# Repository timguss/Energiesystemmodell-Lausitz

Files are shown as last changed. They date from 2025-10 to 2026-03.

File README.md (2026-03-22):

# Energiesystemmodell Lausitz

An interactive, distributed control system for modeling and operating an energy system in the Lausitz region. The system enables real-time control of relays, sensors, motors, and actuators across multiple ESP32 microcontrollers through a Flask-based web interface.

---

## Table of Contents

- [Project Overview](#project-overview)
- [System Architecture](#system-architecture)
- [Features](#features)
- [Hardware Components](#hardware-components)
- [Software Stack](#software-stack)
- [Installation & Setup](#installation--setup)
- [Usage](#usage)
- [API Overview](#api-overview)
- [Project Structure](#project-structure)
- [Future Improvements](#future-improvements)
- [License](#license)

---

## Project Overview

The Energiesystemmodell Lausitz is a physical scale model of an energy system designed for educational and demonstration purposes. It simulates multiple energy sources and components — including a coal power plant, gas plant, electrolyzer, wind turbine, and model railway — all of which can be controlled and monitored in real time via a web-based dashboard.

The system consists of:
- **Multiple ESP32 client devices** that directly control relays, read sensors, and drive actuators
- **One ESP32 Host device** that acts as a central wireless gateway, receiving commands from the web server and forwarding them to the appropriate client via ESP-NOW
- **A Flask web server** (running on a Raspberry Pi or laptop) that exposes a REST API and serves the web UI

Users interact with the system through two frontend interfaces:
- A **landing page** with thematic system cards, scenario buttons, and live sensor values
- A **technical dashboard** for direct relay control, RS232 communication, and device diagnostics

---

## System Architecture

```
┌────────────────────────┐
│   Browser / User       │
│   (Landing / Dashboard)│
└──────────┬─────────────┘
           │ HTTP
┌──────────▼─────────────┐
│   Flask Server         │
│   (Raspberry Pi/Laptop)│
│   app.py + routes/     │
└──────────┬─────────────┘
           │ HTTP (WiFi AP)
┌──────────▼─────────────┐
│   ESP Host             │
│   (WiFi Access Point + │
│    ESP-NOW Gateway)    │
└──┬──────┬──────┬───┬───┘
   │      │      │   │
   │   ESP-NOW   │   │
┌──▼─┐ ┌──▼─┐ ┌─▼─┐ ┌▼──┐ ┌─▼─┐
│ESP1│ │ESP2│ │ESP3│ │ESP4│ │ESP5│
│8x  │ │4x  │ │4x  │ │5x  │ │7x  │
│Relay│ │Relay│ │Relay│ │Relay│ │Strip│
│NTC │ │NTC │ │Motor│ │5x  │ │    │
│RS232│ │    │ │Wind │ │Sensor│ │    │
└────┘ └────┘ └────┘ └────┘ └────┘
```

### Communication Flow

1. The **Flask server** receives HTTP requests from the browser.
2. It forwards commands to the **ESP Host** via HTTP (the Host runs a WebServer over its WiFi AP).
3. The **ESP Host** relays commands to the appropriate **ESP client** using **ESP-NOW** (a connectionless, peer-to-peer protocol that does not require a full TCP/IP stack).
4. Client ESPs send back **status messages** (heartbeats every 2 seconds + immediate ACKs on relay changes) to the Host via ESP-NOW broadcast.
5. The Host caches device states and serves them to the Flask server on demand.

### Why ESP-NOW?

ESP-NOW allows direct peer-to-peer communication between ESP32 devices without requiring a traditional WiFi connection on the client side. This reduces latency, eliminates the need for TCP/IP stack management on clients, and makes the system more robust against network instability.

---

## Features

- **Real-time relay control** — Toggle individual relays on any client ESP via the web UI
- **Scenario execution** — Execute multi-step action sequences (with delays) defined in `scenarios.json`
- **Sensor monitoring** — Live readings from 4–20 mA current-loop sensors calibrated to bar/cm values
- **Temperature monitoring** — NTC thermistor readings from ESP1 and ESP2
- **Flow measurement** — Pulse-counting flow meter on ESP4 (L/min)
- **Motor PWM control** — Variable-speed and direction control of a DC motor on ESP3
- **Wind pin control** — Digital on/off control of a wind output on ESP3
- **RS232 communication** — Send raw serial commands to an MFC (Mass Flow Controller) via ESP1
- **LED flow visualization** — Physical LED strips on ESP5 dynamically mirror website energy flows
- **ACK-based relay confirmation** — The Host waits up to 1500 ms for a relay state acknowledgment from the client before confirming success
- **Device online/offline tracking** — Automatic offline detection after 10 seconds without heartbeat
- **Two UI modes** — Thematic landing page for operators; technical dashboard for developers/engineers
- **Selective polling** — Frontend only polls devices that have previously been seen online, reducing unnecessary requests

---

## Hardware Components

### ESP32 Devices

| Device | Role | Relays | Special Functions |
|---|---|---|---|
| ESP Host | Central gateway / HTTP server | —  | WiFi AP, ESP-NOW hub |
| ESP1 | Gas plant controller | 8 | NTC temperature, RS232 (MFC)  |
| ESP2 | Coal plant controller | 4 | NTC temperature |
| ESP3 | Wind / Train controller  | 4 | DC motor (L298N), wind pin |
| ESP4 | Electrolyzer controller  | 5 | 5× 4–20 mA sensors, flow meter |
| ESP5 | LED Strip controller | — | 7× WS2812B strips for flows |

### Relays

- **ESP1:** Ventil-1, Ventil-2, Heizstab, Zünder, Gasventil, Kühler, MFC, (Unbelegt)
- **ESP2:** Kühler-Kohle, Ventil Turbine, Ventil-Kohle, Heizstab-Kohle
- **ESP3:** Relais 2–5 (general purpose)
- **ESP4:** Elektrolyseur (High-Trigger), Tank füllen, Tank leeren, Durchschalten, Lüfter

### Sensors & Actuators

| Component | Device | Interface | Notes |
|---|---|---|---|
| NTC Thermistors | ESP1, ESP2 | ADC (GPIO34) | β=3950, R₀=10kΩ, voltage divider with 10kΩ |
| 4–20 mA Sensors | ESP4 | ADC (5× pins) | 165Ω shunt resistor, calibrated per sensor |
| Pressure Sensors  | ESP4 | 4–20 mA | Sensors 0–2: pressure (bar) |
| Ultrasonic Sensors| ESP4 | 4–20 mA | Sensors 3–4: distance (cm) |
| Flow Meter | ESP4 | GPIO17 (interrupt) | Pulse-counting, NPN output, FALLING edge |
| DC Motor | ESP3 | L298N (PWM)  | ENA=GPIO32, IN1=GPIO25, IN2=GPIO26 |
| Wind Output | ESP3 | GPIO27 | Digital on/off |
| RS232 / MFC | ESP1 | UART2 (38400 baud) | RX=GPIO16, TX=GPIO17 |
| Standalone Pressure Sensors | External | ADC (GPIO 33–35) | 3× sensors, shared zero point |

---

## Software Stack

### Backend
- **Python 3** with **Flask 3.0**
- **Requests 2.31** for HTTP communication with the ESP Host
- Blueprint-based modular routing (`routes/relays.py`, `routes/scenarios.py`, `routes/leds.py`, `routes/esp3.py`, `routes/debug.py`)

### Frontend
- Vanilla **HTML5 / CSS3 / JavaScript** (no framework dependencies)
- Two pages: `landing.html` (operator UI) + `dashboard.html` (technical UI)
- Polling-based state updates (default: 3–5 second intervals)
- Google Fonts (Inter)

### ESP Firmware
- **Arduino framework** for ESP32 (Arduino IDE / PlatformIO)
- Libraries: `WiFi.h`, `esp_now.h`, `WebServer.h`, `esp_mac.h`

### Communication Protocols

| Layer | Protocol | Used Between |
|---|---|---|
| Browser → Flask | HTTP REST | Browser and Flask server |
| Flask → ESP Host | HTTP (port 80) | Flask server and ESP Host WiFi AP |
| ESP Host → Clients | ESP-NOW | ESP Host and ESP1–5 (peer-to-peer)  |
| ESP1 ↔ MFC | RS232 / UART2  | ESP1 and Mass Flow Controller |

---

## Installation & Setup

### Prerequisites

- Python 3.9+
- Arduino IDE (2.x recommended) or PlatformIO with ESP32 board support
- ESP32 boards flashed with the appropriate firmware

### 1. Flash the ESP Firmware

#### Step 1 — Flash client ESPs first

Flash each client ESP (`ESP_1`, `ESP_2`, `ESP_3`, `ESP_4`) with its corresponding `.ino` sketch. After flashing, open the Serial Monitor at **115200 baud** and note the MAC address printed on boot:

```
ESP-NOW MAC: AA:BB:CC:DD:EE:FF
```

#### Step 2 — Configure the Host

Open `ESP_Host/ESP_Host.ino` and enter the MAC addresses you recorded:

```cpp
uint8_t MAC_ESP1[6] = {0x84, 0x1F, 0xE8, 0x26, 0x58, 0xD8};
uint8_t MAC_ESP2[6] = {0x20, 0x43, 0xA8, 0x6A, 0xFB, 0xDC};
uint8_t MAC_ESP3[6] = {0x20, 0xE7, 0xC8, 0x6B, 0x4F, 0x18};
uint8_t MAC_ESP4[6] = {0x8C, 0x4F, 0x00, 0x2E, 0x59, 0xE8};
uint8_t MAC_ESP5[6] = {0x00, 0x00, 0x00, 0x00, 0x00, 0x00}; // Update with ESP5 MAC
```

Then flash the Host ESP.

#### ESP Host WiFi AP Credentials (default)

```
SSID:     ESP-HOST
Password: espHostPass
Channel:  1
```

> **Important:** ESP-NOW and the WiFi AP must operate on the same channel (channel 1 by default). All client ESPs must also use channel 1.

### 2. Set Up the Flask Server

#### Connect to the ESP Host's WiFi AP

Connect your Raspberry Pi or laptop to the `ESP-HOST` WiFi network.

#### Install Python dependencies

```bash
cd programmierung/website
pip install -r requirements.txt
```

#### Configure the host IP (if needed)

The default host IP is `http://192.168.4.1` (the ESP Host's AP address). Edit `config.py` if your setup differs:

```python
HOST = "http://192.168.4.1"
```

#### Run the Flask server

```bash
python app.py
```

The server starts on `http://0.0.0.0:8000`. Open a browser and navigate to `http://<raspberry-pi-ip>:8000`.

---

## Usage

### Web Interface

| URL | Description |
|---|---|
| `/` | Landing page — thematic system cards, scenarios, sensors |
| `/dashboard` | Technical dashboard — direct relay/motor/RS232 control |

### Scenario Execution

Scenarios are defined in `scenarios.json` as ordered lists of actions. Available action types:

| Type | Fields | Description |
|---|---|---|
| `relay` | `global_idx` or `name`, `val` | Switch a relay on (1) or off (0) |
| `delay` | `ms` | Wait for the given milliseconds |
| `wind`  | `val` | Turn wind output on or off |
| `train` | `pwm`, `dir` | Set motor speed and direction |

Example scenario definition:

```json
"kohlekraftwerk_startup": {
  "name": "Kohlekraftwerk Start",
  "actions": [
    { "type": "relay", "global_idx": 9, "val": 1 },
    { "type": "delay", "ms": 1500 },
    { "type": "relay", "global_idx": 10, "val": 1 }
  ]
}
```

### Global Relay Index Mapping

| Global Index | Device | Device Index | Name |
|---|---|---|---|
| 1–8 | ESP1 | 0–7 | Ventil-1 … Unbelegt |
| 9–12 | ESP2 | 0–3 | Kühler-Kohle … Heizstab-Kohle |
| 13–17 | ESP4 | 0–4 | Elektrolyseur … Lüfter |
| 18–21 | ESP3 | 0–3 | Relais 2–5 |

---

## API Overview

All endpoints are served by the Flask server on port 8000.

### Relay Control

| Method | Endpoint | Body / Params | Description |
|---|---|---|---|
| POST | `/api/relay/set` | `{ "global_idx": 1, "val": 1 }` | Set a relay on or off |

### Device State

| Method | Endpoint | Description |
|---|---|---|
| GET | `/api/device_state/<device>` | Get last known state of `esp1`–`esp4`  |
| GET | `/api/device_meta/<device>`  | Get relay count and names for a device |

**Example response for `esp4`:**
```json
{
  "code": 200,
  "body": {
    "relays": [0, 1, 0, 0, 1],
    "sensors": [
      { "current": 8.45, "pressure": 1.23 },
      ...
    ],
    "flow": 3.5
  },
  "offline": false
}
```

### Scenarios

| Method | Endpoint | Body | Description |
|---|---|---|---|
| GET | `/api/scenarios` | — | List all available scenarios |
| POST | `/api/scenario/execute` | `{ "scenario": "kohlekraftwerk_startup" }`  | Execute a scenario by key |

### ESP3 Controls

| Method | Endpoint | Body | Description |
|---|---|---|---|
| GET | `/api/esp3/state` | — | Get wind and motor state |
| POST | `/api/esp3/set_wind`  | `{ "val": 1 }` | Turn wind on or off |
| POST | `/api/esp3/set_pwm` | `{ "pwm": 128, "dir": 1 }` | Set motor speed/direction|

### RS232

| Method | Endpoint | Body | Description |
|---|---|---|---|
| POST | `/api/rs232`  | `{ "cmd": ":06030101213E80", "timeout": 500 }` | Send raw RS232 command via ESP1 |
| POST | `/api/leds/sync` | `{ "flows": { "coal": [true], ... } }` | Sync flows with ESP5 strips |
| POST | `/api/leds/test` | `{ "mode": "green" }` | Hardware test for all LEDs |

### Debug / Status

| Method | Endpoint | Description |
|---|---|---|
| GET | `/api/debug/host` | Check if the Host ESP is reachable |
| GET | `/api/clients` | Get online/offline status of all clients  |
| GET | `/api/sensors/meta`  | Get sensor configuration for the frontend |

---

## Project Structure

```
.
├── README.md
└── programmierung/
    ├── esp code/
    │   ├── ESP_Host/
    │   │   └── ESP_Host.ino         # Central gateway: WiFi AP + ESP-NOW hub + HTTP server
    │   ├── ESP_1/
    │   │   └── ESP_1.ino            # 8× relay, NTC temp, RS232 (MFC)
    │   ├── ESP_2/
    │   │   └── ESP_2.ino            # 4× relay, NTC temp
    │   ├── ESP_3/
    │   │   └── ESP_3.ino            # 4× relay, DC motor, wind output
    │   ├── ESP_4/
    │   │   └── ESP_4.ino            # 5× relay, 5× 4–20mA sensors, flow meter
    │   ├── ESP_5/
    │   │   └── ESP_5.ino            # 7× LED strip controller
    │   ├── Drucksensoren/
    │   │   └── Drucksensoren.ino    # Standalone pressure sensor test sketch
    │   ├── Ralays-4/
    │   │   └── Ralays-4.ino         # Simple 4-relay cycling test sketch
    │   └── tests/
    │       ├── layout.html          # Standalone HTML UI prototype
    │       └── test/
    │           └── test.ino         # Flow meter calibration sketch
    └── website/
        ├── app.py                   # Flask application entry point
        ├── config.py                # Central config: HOST, relay map, sensor calibration, scenarios
        ├── esp_client.py            # Low-level HTTP client for ESP Host communication
        ├── requirements.txt
        ├── scenarios.json           # Scenario definitions (actions, delays)
        ├── routes/
        │   ├── __init__.py
        │   ├── relays.py            # /api/relay/set, /api/device_state, /api/device_meta
        │   ├── scenarios.py         # /api/scenarios, /api/scenario/execute
        │   ├── esp3.py              # /api/esp3/*, /api/rs232
        │   └── debug.py             # /api/debug/host, /api/clients
        ├── static/
        │   ├── app.js               # Dashboard page JavaScript
        │   ├── landing.js           # Landing page JavaScript
        │   ├── style.css            # Dashboard styles
        │   └── landing.css          # Landing page styles
        └── templates/
            ├── dashboard.html       # Technical control dashboard
            └── landing.html         # Operator-facing landing page
```

---

## Future Improvements

- [ ] **WebSocket / Server-Sent Events** — Replace HTTP polling with push-based updates for lower latency and reduced server load
- [ ] **Authentication** — Add basic auth or token-based access control to the Flask API
- [ ] **Persistent state storage** — Log relay states and sensor readings to a database (e.g. SQLite or InfluxDB) for historical analysis
- [ ] **Flow meter calibration UI** — Allow the K_FACTOR to be set from the web UI without reflashing firmware
- [ ] **RS232 command library** — Build a structured command library for the MFC instead of raw hex input
- [ ] **Sensor calibration UI** — Allow `i_zero`, `i_full`, and `max_val` to be adjusted at runtime via the dashboard
- [ ] **ESP4 pressure display on landing page** — Wire up the existing sensor cards to show live pressure bar graphs
- [ ] **Scenario editor** — UI for creating and editing scenarios without manually editing `scenarios.json`
- [ ] **Multi-language support** — Currently the UI is in German; adding English would increase accessibility
- [ ] **OTA firmware updates** — Enable over-the-air updates for the ESP devices

---

## License

This project is currently unlicensed. Add a `LICENSE` file to define usage terms.

---

*Energiesystemmodell Lausitz — Interaktive Steuerung für erneuerbare Energiesysteme*

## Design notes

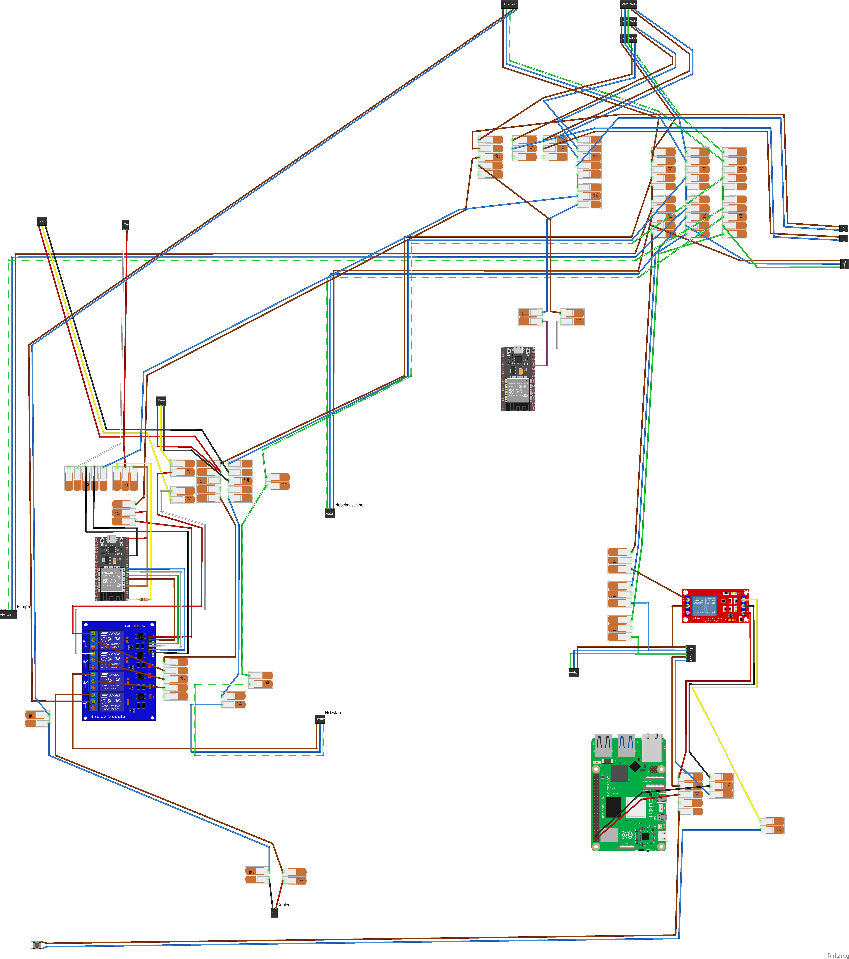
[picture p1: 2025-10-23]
verkabelung/Tisch-1.png

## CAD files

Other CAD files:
website/models/Blender/Tisch-extured-wood.blend
website/models/Blender/Tischv57.blend
website/models/Blender/assets/materials/magic-glass_280b4756-c25d-46e4-b795-ee6590a0f657/magic-glass_90b6109c-63bb-433e-94c7-02eb88bf1149.blend
website/models/Blender/assets/materials/wood_4a3f386c-fc55-4a7d-914b-ec320360598c/wood_c2ab5ce4-03af-4618-8913-53a9fba6e7ce.blend
website/models/Blender/body.blend

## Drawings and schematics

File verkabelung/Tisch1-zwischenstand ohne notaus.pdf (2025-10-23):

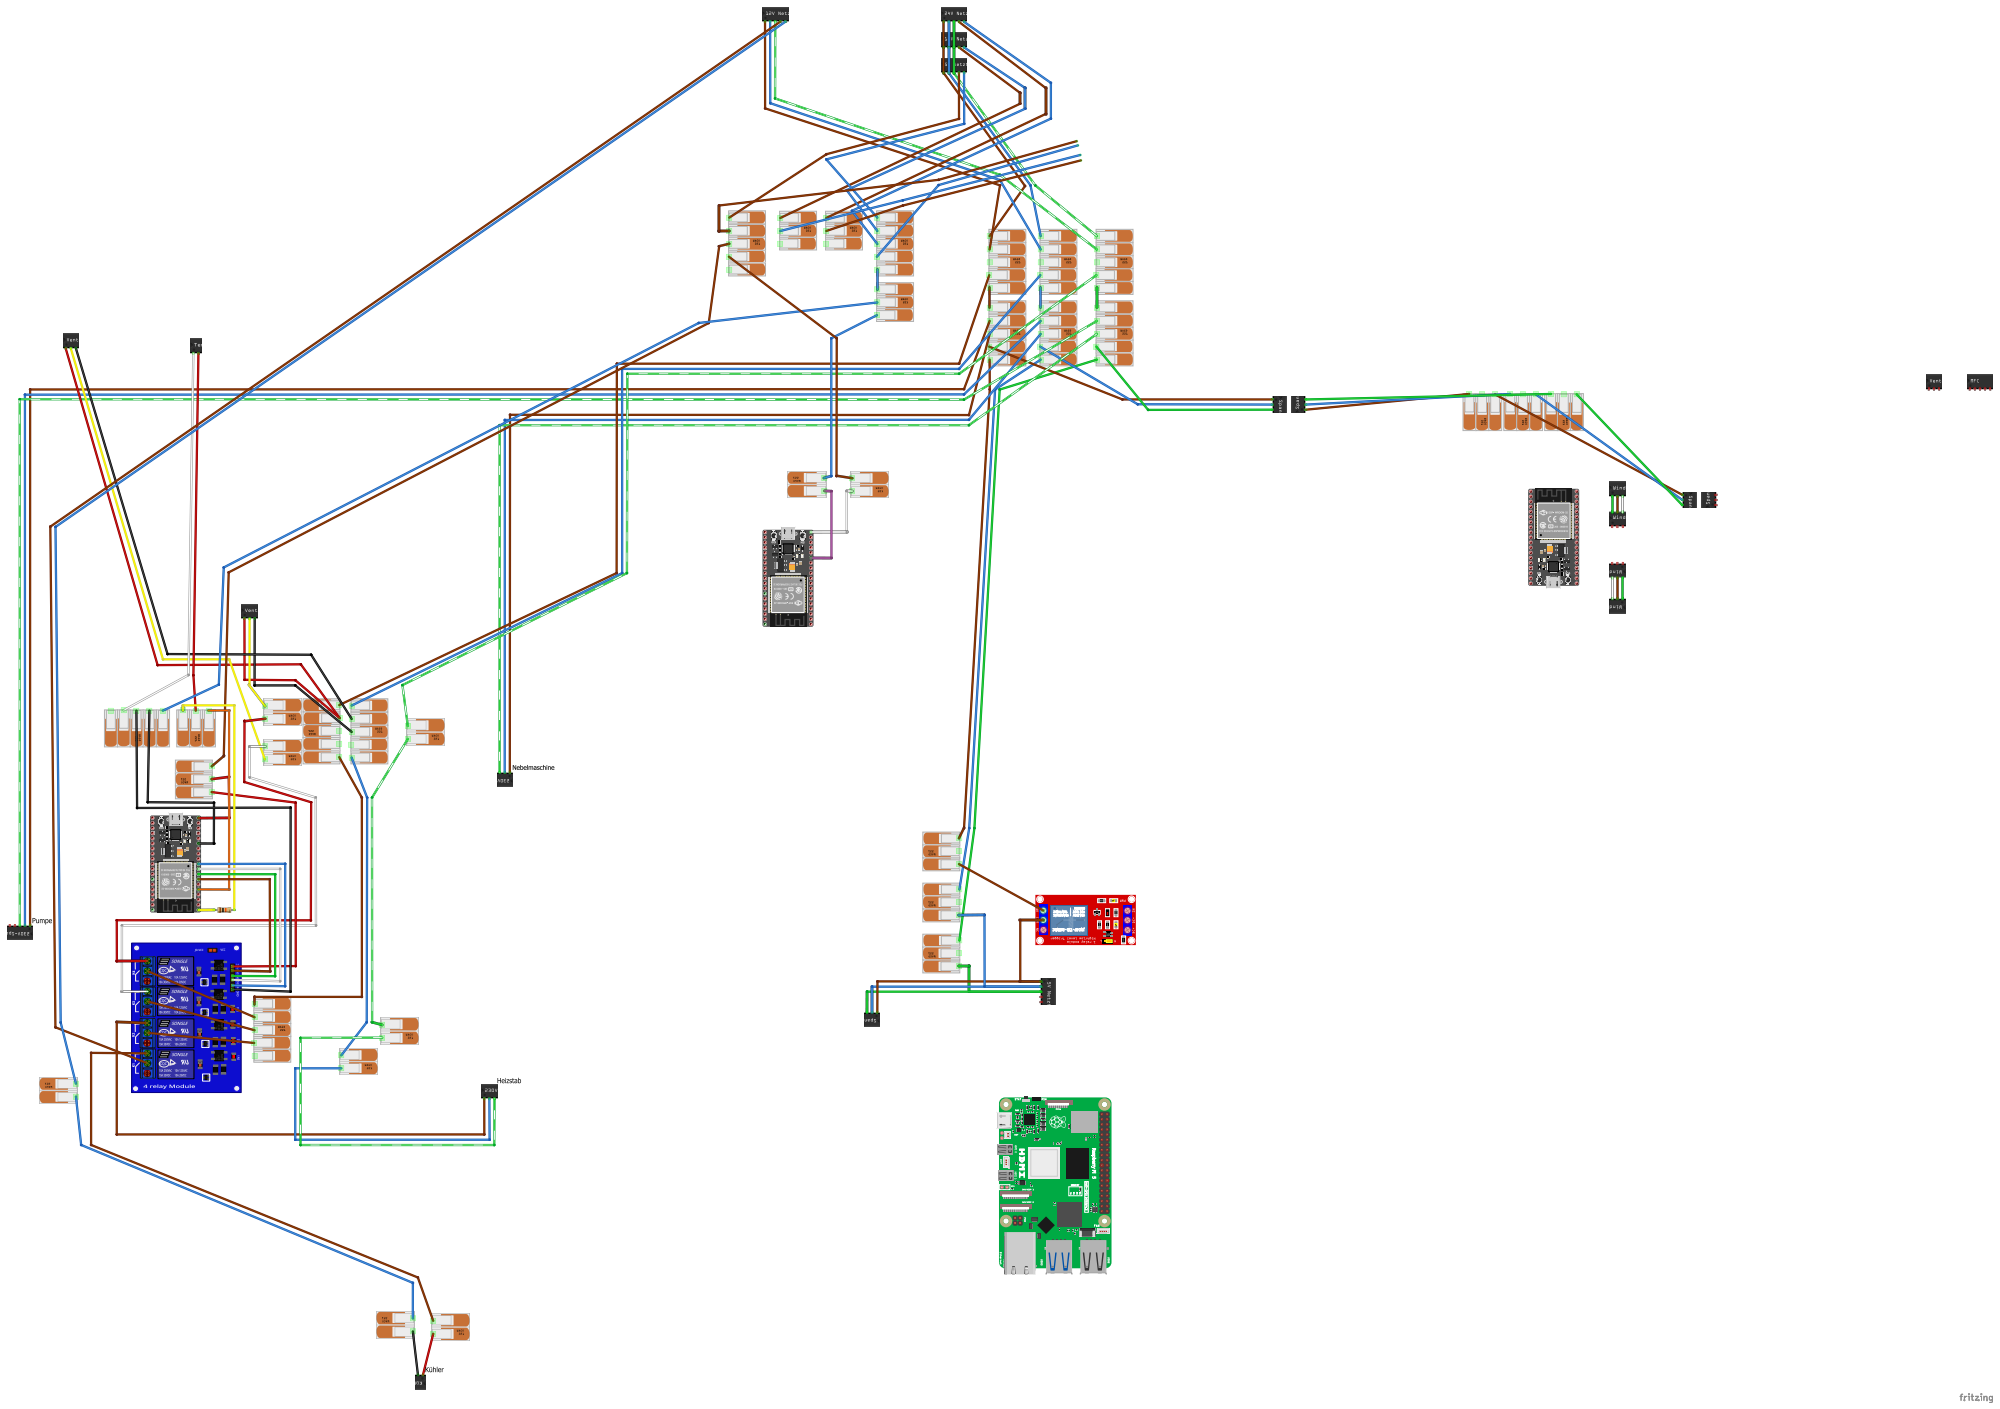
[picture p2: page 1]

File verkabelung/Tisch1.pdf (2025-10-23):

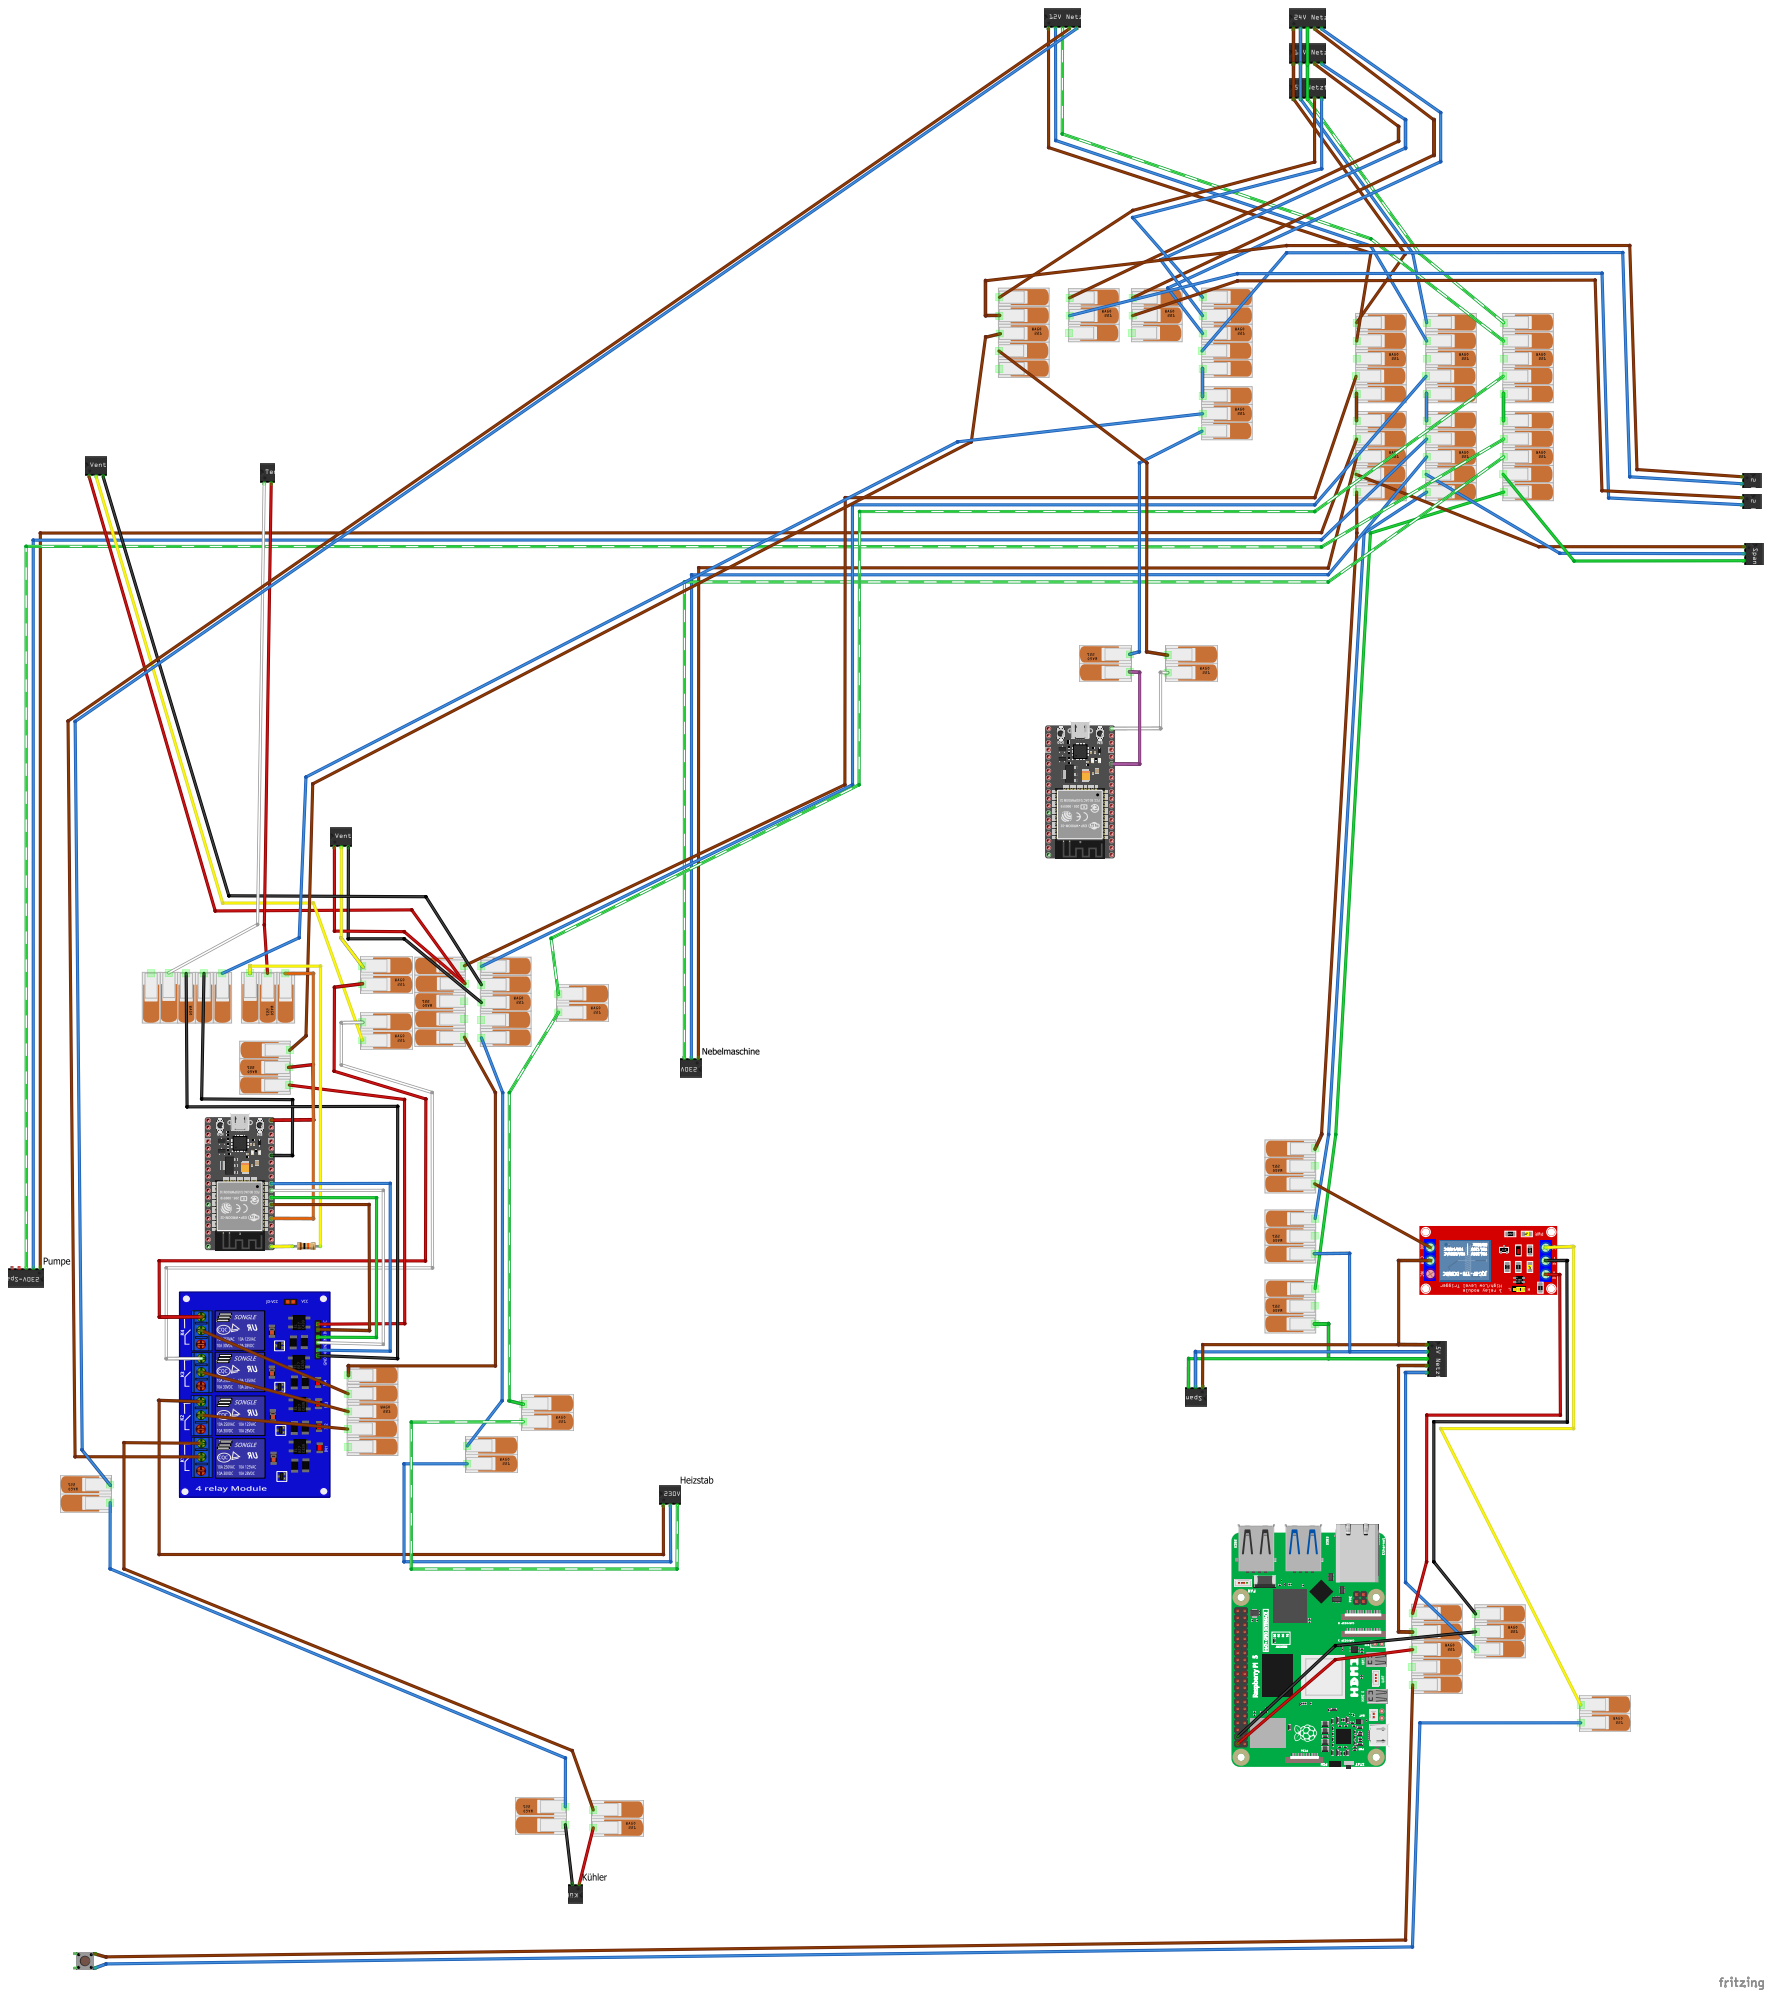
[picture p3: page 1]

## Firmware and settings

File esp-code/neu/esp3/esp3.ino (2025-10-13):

// esp3_dashboard_forwarder_final_no_rebuild.ino
// ESP3: SoftAP + Dashboard + Forwarder + lokale Steuerung (Zug PWM, Windrad Motor+LED)
// Verbesserte Dashboard-JS: aktualisiert DOM inkrementell, verhindert Fokusverlust / Eingabeverlust
// Benötigt: ArduinoJson (6.x)

#include <WiFi.h>
#include <WebServer.h>
#include <ArduinoJson.h>
#include <HTTPClient.h>

const char* AP_SSID = "ESP-AP";
const char* AP_PASS = "espap123";
IPAddress apIP(192,168,4,1);

WebServer server(80);
const char* DEVICE_ID = "esp3";

// --- Hardware: Zug + Windrad ---
const int pwmPin = 25;
const uint32_t pwmFreq = 5000;
const uint8_t pwmRes = 8;
int pwmValue = 0;

const int motorPin = 32;
bool motorOn = false;

const int ledPin = 33;
bool ledOn = false;

const int LED_PIN = 2;

// --- Clients storage ---
struct ClientInfo {
  String id;
  String ip;
  String lastStatusJson;
  unsigned long lastSeen;
};
#define MAX_CLIENTS 8
ClientInfo clients[MAX_CLIENTS];

// --- Self update ---
const unsigned long SELF_UPDATE_INTERVAL = 4000;
unsigned long lastSelfUpdate = 0;

// --- Helpers ---
int findClientSlotById(const String &id){
  for(int i=0;i<MAX_CLIENTS;i++) if(clients[i].id == id) return i;
  return -1;
}

void printClients(){
  Serial.println("--- Clients ---");
  for(int i=0;i<MAX_CLIENTS;i++){
    if(clients[i].id.length()){
      Serial.printf("[%d] id=%s ip=%s lastSeen=%lu\n", i, clients[i].id.c_str(), clients[i].ip.c_str(), clients[i].lastSeen);
    }
  }
  Serial.println("---------------");
}

void cleanupStaleClients(){
  unsigned long now = millis();
  for(int i=0;i<MAX_CLIENTS;i++){
    if(clients[i].id.length()){
      if(clients[i].id == String(DEVICE_ID)) continue; // keep self
      if(now - clients[i].lastSeen > 30000UL){
        Serial.printf("Client %s stale (lastSeen %lu), removing\n", clients[i].id.c_str(), clients[i].lastSeen);
        clients[i].id=""; clients[i].ip=""; clients[i].lastStatusJson=""; clients[i].lastSeen=0;
      }
    }
  }
}

// --- Dashboard HTML (improved JS: incremental update) ---
const char dashboard_html[] PROGMEM = R"rawliteral(
<!doctype html>
<html>
<head>
  <meta charset='utf-8'>
  <meta name='viewport' content='width=device-width,initial-scale=1'/>
  <title>ESP Dashboard</title>
  <style>
    body{font-family:Arial,Helvetica,sans-serif;margin:12px}
    h1{font-size:20px}
    .dev{border:1px solid #ccc;padding:8px;margin:8px 0;border-radius:6px;background:#fafafa}
    .dev-head{display:flex;justify-content:space-between;align-items:center}
    .small{font-size:12px;color:#666}
    .controls{margin-top:8px}
    .label-inline{display:inline-block;margin-right:8px}
    .tip{font-size:11px;color:#666;margin-top:6px}
    input[type="text"]{width:60%}
  </style>
</head>
<body>
  <h1>ESP Dashboard</h1>
  <div id='main'>loading...</div>
<script>
/* incremental dashboard updater
   - builds device container once
   - updates values (temp, relay states, pwm, motor, led)
   - preserves RS232 input value & focus
*/

const POLL_MS = 1500;
let devicesMap = {}; // id -> { container, elems... }

function makeDeviceContainer(id, ip){
  const container = document.createElement('div');
  container.className = 'dev';
  container.id = 'dev_' + id;

  const head = document.createElement('div');
  head.className = 'dev-head';
  const title = document.createElement('div');
  title.innerHTML = '<b>' + id + '</b> <span class="small">(' + ip + ')</span>';
  const lastSeenEl = document.createElement('div');
  lastSeenEl.className = 'small';
  lastSeenEl.id = 'ls_' + id;
  head.appendChild(title);
  head.appendChild(lastSeenEl);
  container.appendChild(head);

  const body = document.createElement('div');
  body.className = 'controls';
  // placeholders
  const tempEl = document.createElement('div'); tempEl.id = 'temp_' + id;
  body.appendChild(tempEl);

  const relaysEl = document.createElement('div'); relaysEl.id = 'relays_' + id;
  body.appendChild(relaysEl);

  // RS232 area (only for esp1, will be toggled visible later)
  const rsDiv = document.createElement('div'); rsDiv.id = 'rsdiv_' + id;
  rsDiv.style.display = 'none';
  const rsInput = document.createElement('input'); rsInput.type='text'; rsInput.id = 'rs_in_' + id; rsInput.placeholder='Text to send';
  const rsBtn = document.createElement('button'); rsBtn.textContent='Send';
  const rsResp = document.createElement('span'); rsResp.id = 'rs_resp_' + id;
  rsBtn.addEventListener('click', ()=> sendRS(id));
  rsDiv.appendChild(rsInput); rsDiv.appendChild(rsBtn); rsDiv.appendChild(rsResp);
  body.appendChild(rsDiv);

  // ESP3-specific controls (pwm + motor + led)
  const localDiv = document.createElement('div'); localDiv.id = 'local_' + id;
  localDiv.style.display='none';
  // pwm
  const pwmLabel = document.createElement('label'); pwmLabel.className='label-inline'; pwmLabel.textContent='Zug PWM: ';
  const pwmSlider = document.createElement('input'); pwmSlider.type='range'; pwmSlider.min=0; pwmSlider.max=255; pwmSlider.id='pwm_'+id;
  const pwmVal = document.createElement('span'); pwmVal.id='pwmv_'+id; pwmVal.textContent='0';
  pwmSlider.addEventListener('input', ()=> {
    pwmVal.textContent = pwmSlider.value;
    sendCmd(id, 'pwm:' + pwmSlider.value);
  });
  pwmLabel.appendChild(pwmSlider); pwmLabel.appendChild(pwmVal);
  localDiv.appendChild(pwmLabel);
  // motor button
  const motorBtn = document.createElement('button'); motorBtn.id='motor_'+id;
  motorBtn.addEventListener('click', ()=> {
    const cur = motorBtn.getAttribute('data-on') === '1';
    sendCmd(id, '0:' + (cur ? 0 : 1));
  });
  localDiv.appendChild(document.createElement('div')).appendChild(motorBtn);
  // led button
  const ledBtn = document.createElement('button'); ledBtn.id='led_'+id;
  ledBtn.addEventListener('click', ()=> {
    const cur = ledBtn.getAttribute('data-on') === '1';
    sendCmd(id, '1:' + (cur ? 0 : 1));
  });
  localDiv.appendChild(document.createElement('div')).appendChild(ledBtn);

  body.appendChild(localDiv);

  // tip
  const tip = document.createElement('div'); tip.className='tip';
  tip.textContent = 'Tip: Relays/RS232 send raw text to device /cmd (e.g. 0:1 or rs232:HELLO)';
  body.appendChild(tip);

  container.appendChild(body);
  return { container, lastSeenEl, tempEl, relaysEl, rsDiv, rsInput, rsResp, localDiv, pwmSlider, pwmVal, motorBtn, ledBtn };
}

async function refreshOnce(){
  try {
    const res = await fetch('/status', {cache:'no-store'});
    const j = await res.json();
    const seen = new Set();
    for(const d of j.devices){
      seen.add(d.id);
      if(!devicesMap[d.id]){
        const el = makeDeviceContainer(d.id, d.ip);
        document.getElementById('main').appendChild(el.container);
        devicesMap[d.id] = el;
      }
      updateDevice(d);
    }
    // remove devices not seen
    for(const id in devicesMap){
      if(!seen.has(id)){
        const el = document.getElementById('dev_' + id);
        if(el) el.remove();
        delete devicesMap[id];
      }
    }
  } catch(e){
    console.error('refresh error', e);
  }
}

function updateDevice(d){
  const el = devicesMap[d.id];
  if(!el) return;
  // lastSeen
  el.lastSeenEl.textContent = 'lastSeen: ' + new Date(d.lastSeen).toLocaleTimeString();

  // TEMP
  if(d.status && d.status.temp !== undefined){
    el.tempEl.innerHTML = 'Temperatur: <b>' + (d.status.temp.toFixed(1)) + ' °C</b>';
  } else {
    el.tempEl.innerHTML = '';
  }

  // RELAYS: create checkboxes only once, then update checked state
  if(d.status && Array.isArray(d.status.relays)){
    // if not built yet, create them
    if(!el.relaysEl.hasChildNodes() || el.relaysEl.getAttribute('data-built') !== '1'){
      el.relaysEl.innerHTML = ''; // ensure empty
      const names = (d.status.relay_names && Array.isArray(d.status.relay_names)) ? d.status.relay_names : [];
      for(let i=0;i<d.status.relays.length;i++){
        const label = document.createElement('label');
        label.className='label-inline';
        const cb = document.createElement('input');
        cb.type='checkbox';
        cb.id = d.id + '_r_' + i;
        // attach change handler
        cb.addEventListener('change', (ev)=> {
          const val = ev.target.checked ? 1 : 0;
          sendCmd(d.id, i + ':' + val);
        });
        const txt = document.createTextNode((names[i] ? names[i] : ('R'+i)));
        label.appendChild(cb);
        label.appendChild(txt);
        el.relaysEl.appendChild(label);
      }
      el.relaysEl.setAttribute('data-built','1');
    }
    // update checked state (without triggering change event)
    for(let i=0;i<d.status.relays.length;i++){
      const cb = document.getElementById(d.id + '_r_' + i);
      if(cb){
        cb.checked = !!d.status.relays[i];
      }
    }
  } else {
    // no relays
    el.relaysEl.innerHTML = '';
    el.relaysEl.removeAttribute('data-built');
  }

  // RS232 visible only for esp1
  if(d.id === 'esp1'){
    el.rsDiv.style.display = '';
    // don't overwrite rsInput.value to preserve typing
  } else {
    el.rsDiv.style.display = 'none';
  }

  // ESP3 local controls
  if(d.id === 'esp3'){
    el.localDiv.style.display = '';
    // pwm
    const pwmValNum = (d.status && d.status.pwm !== undefined) ? d.status.pwm : 0;
    if(el.pwmSlider.value != pwmValNum){
      el.pwmSlider.value = pwmValNum;
      el.pwmVal.textContent = pwmValNum;
    }
    // motor button
    const motorState = (d.status && d.status.motor !== undefined) ? (d.status.motor==1) : false;
    el.motorBtn.setAttribute('data-on', motorState ? '1':'0');
    el.motorBtn.textContent = motorState ? 'Stop' : 'Start';
    // led button
    const ledState = (d.status && d.status.led !== undefined) ? (d.status.led==1) : false;
    el.ledBtn.setAttribute('data-on', ledState ? '1':'0');
    el.ledBtn.textContent = ledState ? 'LED Off' : 'LED On';
  } else {
    el.localDiv.style.display = 'none';
  }
}

async function sendCmd(id, cmd){
  try{
    const res = await fetch('/set', {
      method:'POST',
      headers:{'Content-Type':'application/json'},
      body: JSON.stringify({id:id, cmd:cmd})
    });
    const j = await res.json();
    return j;
  } catch(e){
    console.error('sendCmd error', e);
  }
}

async function sendRS(id){
  const el = devicesMap[id];
  if(!el) return;
  const val = el.rsInput.value;
  if(!val) return;
  const r = await sendCmd(id, 'rs232:' + val);
  if(r && r.resp){
    el.rsResp.innerText = ' → ' + (r.resp ? r.resp.substr(0,200) : '');
    setTimeout(()=>{ el.rsResp.innerText = ''; }, 5000);
  }
}

let refreshTimer = null;
function startPolling(){
  if(refreshTimer) clearInterval(refreshTimer);
  refreshOnce(); // initial
  refreshTimer = setInterval(refreshOnce, POLL_MS);
}

window.onload = function(){
  document.getElementById('main').innerHTML = ''; // clear placeholder
  startPolling();
};
</script>
</body>
</html>
)rawliteral";

String getDashboardPage(){
  return String(dashboard_html);
}

// --- HTTP Handlers ---
void handleRoot(){
  Serial.println("HTTP GET / -> serving dashboard");
  server.send(200, "text/html", getDashboardPage());
}

void handleStatus(){
  Serial.println("HTTP GET /status");
  DynamicJsonDocument doc(4096);
  JsonArray arr = doc.createNestedArray("devices");
  for(int i=0;i<MAX_CLIENTS;i++){
    if(clients[i].id.length()){
      DynamicJsonDocument sub(2048);
      DeserializationError derr = deserializeJson(sub, clients[i].lastStatusJson);
      JsonObject obj = arr.createNestedObject();
      obj["id"] = clients[i].id;
      obj["ip"] = clients[i].ip;
      obj["lastSeen"] = clients[i].lastSeen;
      if(!derr) obj["status"] = sub.as<JsonObject>();
      else obj["status"] = JsonObject();
    }
  }
  String out;
  serializeJson(doc, out);
  Serial.println("DEBUG /status JSON:");
  Serial.println(out);
  server.send(200, "application/json", out);
}

// improved handleRegister: correctly serialize incoming status variant
void handleRegister(){
  Serial.println("HTTP POST /register");
  if(server.hasArg("plain")==false){ server.send(400,"text/plain","no body"); return; }
  String body = server.arg("plain");
  Serial.println("Body: " + body);

  DynamicJsonDocument doc(4096);
  DeserializationError err = deserializeJson(doc, body);
  if(err){
    Serial.print("deserializeJson error: ");
    Serial.println(err.c_str());
    server.send(400,"text/plain","bad json");
    return;
  }

  String id = doc["id"].as<String>();
  String ip = doc["ip"].as<String>();
  JsonVariant status = doc["status"];

  // debug show parsed status
  {
    String tmp;
    serializeJson(status, tmp);
    Serial.println("Parsed status (serialized): " + tmp);
  }

  int slot = findClientSlotById(id);
  if(slot == -1){
    for(int i=0;i<MAX_CLIENTS;i++){
      if(clients[i].id.length()==0){ slot=i; break; }
    }
  }
  if(slot == -1){
    Serial.println(" -> no slots free");
    server.send(500,"text/plain","no slots");
    return;
  }

  clients[slot].id = id;
  clients[slot].ip = ip;

  // serialize status variant directly into string (this preserves object contents)
  String st;
  if(!status.isNull()){
    serializeJson(status, st);
  } else {
    st = "{}";
  }

  clients[slot].lastStatusJson = st;
  clients[slot].lastSeen = millis();

  server.send(200,"text/plain","ok");
  Serial.printf("Registered %s @ %s (slot %d)\n", id.c_str(), ip.c_str(), slot);
  Serial.println("Stored lastStatusJson: " + st);
  printClients();
}

void applyLocalCmd(const String &cmd){
  if(cmd.startsWith("pwm:")){
    int val = cmd.substring(4).toInt();
    val = constrain(val, 0, 255);
    pwmValue = val;
    ledcWrite(pwmPin, pwmValue);
    Serial.printf("Local PWM set to %d\n", pwmValue);
  } else {
    int colon = cmd.indexOf(':');
    if(colon>0){
      int idx = cmd.substring(0,colon).toInt();
      int val = cmd.substring(colon+1).toInt();
      if(idx == 0){
        motorOn = (val == 1);
        digitalWrite(motorPin, motorOn ? HIGH : LOW);
        Serial.printf("Motor -> %d\n", motorOn?1:0);
      } else if(idx == 1){
        ledOn = (val == 1);
        digitalWrite(ledPin, ledOn ? HIGH : LOW);
        Serial.printf("LED -> %d\n", ledOn?1:0);
      } else {
        Serial.printf("Unknown local idx %d\n", idx);
      }
    }
  }
}

void handleSet(){
  Serial.println("HTTP POST /set");
  if(server.hasArg("plain")==false){ server.send(400,"text/plain","no body"); return; }
  String body = server.arg("plain");
  Serial.println("Body: " + body);

  DynamicJsonDocument doc(512);
  if(deserializeJson(doc, body)){
    Serial.println(" -> bad json in /set");
    server.send(400,"text/plain","bad json");
    return;
  }
  String id = doc["id"].as<String>();
  String cmd = doc["cmd"].as<String>();

  if(id == String(DEVICE_ID)){
    Serial.println(" -> applying local cmd: " + cmd);
    applyLocalCmd(cmd);
    // update stored own status immediately
    DynamicJsonDocument sdoc(256);
    JsonObject s = sdoc.createNestedObject("status");
    s["pwm"] = pwmValue;
    s["motor"] = motorOn ? 1 : 0;
    s["led"] = ledOn ? 1 : 0;
    String st; serializeJson(s, st);
    int slot = findClientSlotById(String(DEVICE_ID));
    if(slot == -1){
      for(int i=0;i<MAX_CLIENTS;i++){ if(clients[i].id.length()==0){ slot=i; break; } }
    }
    if(slot!=-1){ clients[slot].id = String(DEVICE_ID); clients[slot].ip = apIP.toString(); clients[slot].lastStatusJson = st; clients[slot].lastSeen = millis(); }
    server.send(200,"application/json","{\"code\":200}");
    return;
  }

  // find client ip
  String targetIp = "";
  for(int i=0;i<MAX_CLIENTS;i++){
    if(clients[i].id == id){ targetIp = clients[i].ip; break; }
  }
  if(targetIp == ""){
    Serial.println(" -> unknown id " + id);
    server.send(404,"text/plain","unknown id");
    return;
  }

  // forward http POST to http://<targetIp>/cmd with raw body = cmd
  HTTPClient http;
  String url = "http://" + targetIp + "/cmd";
  Serial.println("Forwarding to " + url + " cmd='" + cmd + "'");
  http.begin(url);
  http.addHeader("Content-Type","text/plain");
  int code = http.POST(cmd);
  String resp = http.getString();
  http.end();
  Serial.printf(" -> remote returned %d, resp len=%d\n", code, resp.length());

  String reply = "{\"code\":" + String(code) + ",\"resp\":\"" + String(resp) + "\"}";
  server.send(200,"application/json",reply);
  Serial.printf("Forwarded to %s: %s -> %d\n", targetIp.c_str(), cmd.c_str(), code);
}

// --- Setup & Loop ---
void setup(){
  Serial.begin(115200);
  delay(50);
  Serial.println("\n=== ESP3 AP Server Starting ===");

  pinMode(LED_PIN, OUTPUT);
  digitalWrite(LED_PIN, LOW);
  pinMode(motorPin, OUTPUT);
  pinMode(ledPin, OUTPUT);
  digitalWrite(motorPin, LOW);
  digitalWrite(ledPin, LOW);

  bool ledcOk = ledcAttach(pwmPin, pwmFreq, pwmRes);
  Serial.printf("ledcAttach(pin=%d,freq=%u,res=%u) -> %s\n", pwmPin, pwmFreq, pwmRes, ledcOk ? "OK":"FAIL");
  ledcWrite(pwmPin, pwmValue);

  WiFi.mode(WIFI_AP);
  bool confOk = WiFi.softAPConfig(apIP, apIP, IPAddress(255,255,255,0));
  Serial.printf("softAPConfig returned: %s\n", confOk ? "true":"false");
  int apChannel = 1;
  bool apOk = WiFi.softAP(AP_SSID, AP_PASS, apChannel);
  Serial.printf("softAP returned: %s (channel %d)\n", apOk ? "true":"false", apChannel);
  Serial.print("AP gestartet: "); Serial.println(AP_SSID);
  Serial.print("AP-IP: "); Serial.println(WiFi.softAPIP());

  server.on("/", handleRoot);
  server.on("/status", handleStatus);
  server.on("/register", handleRegister);
  server.on("/set", handleSet);
  server.begin();
  Serial.println("Webserver gestartet on port 80");

  // prime own slot so dashboard shows esp3 at start
  DynamicJsonDocument sdoc(256);
  JsonObject s = sdoc.createNestedObject("status");
  s["pwm"] = pwmValue;
  s["motor"] = motorOn ? 1 : 0;
  s["led"] = ledOn ? 1 : 0;
  String st; serializeJson(s, st);
  int slot = findClientSlotById(String(DEVICE_ID));
  if(slot == -1){
    for(int i=0;i<MAX_CLIENTS;i++){ if(clients[i].id.length()==0){ slot=i; break; } }
  }
  if(slot != -1){
    clients[slot].id = String(DEVICE_ID);
    clients[slot].ip = apIP.toString();
    clients[slot].lastStatusJson = st;
    clients[slot].lastSeen = millis();
  }
  printClients();
  lastSelfUpdate = millis();
}

void loop(){
  server.handleClient();
  if(millis() - lastSelfUpdate >= SELF_UPDATE_INTERVAL){
    int slot = findClientSlotById(String(DEVICE_ID));
    if(slot != -1){ clients[slot].lastSeen = millis(); }
    lastSelfUpdate = millis();
  }
  cleanupStaleClients();
}

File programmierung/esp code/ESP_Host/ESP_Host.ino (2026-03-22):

/*
 * ESP_Host — ESP-NOW Gateway + WiFi AP für Raspberry Pi
 *
 * Kommunikation:
 *   - Raspberry Pi  →  HTTP (WiFi AP, unverändert)
 *   - ESP1–ESP4    →  ESP-NOW (direkt, kein TCP/IP)
 *
 * SETUP (einmalig):
 *   1. Flashe jeden ESP1–4 und lese im Serial Monitor die Zeile:
 *      "ESP-NOW MAC: AA:BB:CC:DD:EE:FF"
 *   2. Trage die MACs unten in MAC_ESP1 bis MAC_ESP4 ein.
 *   3. Flashe diesen Host-Code.
 */

#include <WiFi.h>
#include <WebServer.h>
#include <esp_now.h>
#include "secrets.h"  // WiFi credentials — NOT in git, see secrets.h.example

// ============================================================================
// MAC-ADRESSEN DER CLIENTS — hier eintragen nach erstem Flashen!
// ============================================================================
uint8_t MAC_ESP1[6] = {0x84, 0x1F, 0xE8, 0x26, 0x58, 0xD8};
uint8_t MAC_ESP2[6] = {0x20, 0x43, 0xA8, 0x6A, 0xFB, 0xDC};
uint8_t MAC_ESP3[6] = {0x20, 0xE7, 0xC8, 0x6B, 0x4F, 0x18};
uint8_t MAC_ESP4[6] = {0x8C, 0x4F, 0x00, 0x2E, 0x59, 0xE8};
uint8_t MAC_ESP5[6] = {0x00, 0x00, 0x00, 0x00, 0x00, 0x00}; // TODO: MAC von ESP5 eintragen

// ============================================================================
// WIFI AP
// ============================================================================
// AP_SSID and AP_PASSWORD are defined in secrets.h (gitignored)
const int   AP_CHANNEL  = 1; // ESP-NOW + AP müssen denselben Kanal nutzen!

WebServer server(80);

// ============================================================================
// ESP-NOW NACHRICHTENSTRUKTUREN
// ============================================================================

// Host → Client: Befehl
typedef struct __attribute__((packed)) {
  char  cmd[12];   // "RELAY", "TRAIN", "WIND", "RS232"
  int16_t idx;
  int16_t val;
  int16_t extra;   // z.B. Richtung für Motor
  char  payload[64]; // Neu für RS232-Kommandos
} CmdMsg;

// Client → Host: Status-Antwort
typedef struct __attribute__((packed)) {
  char    device[8];        // "esp1", "esp2", usw.
  int16_t relays[8];        // Relay-Zustände (bis zu 8)
  float   sensors[5];       // Sensor-Rohwerte (mA)
  float   temp;             // Temperatur (NAN wenn nicht vorhanden)
  float   flow;             // Durchfluss (nur ESP4)
  int16_t pwm;              // Motor-PWM (nur ESP3)
  int8_t  forward;          // Motor-Richtung (nur ESP3)
  int8_t  running;          // Wind-Status (nur ESP3)
  int8_t  relay_count;      // Anzahl verfügbarer Relais
  int8_t  sensor_count;     // Anzahl gültiger Sensoren
  uint8_t rs232_seq;        // Sequenznummer für RS232-Antworten
  char    last_rs232_res[64]; // Letzte RS232-Antwort
} StatusMsg;

// Gespeicherter Zustand pro Client
struct ClientState {
  bool    online;
  unsigned long lastSeen;
  StatusMsg status;
  // Pending acknowledgment
  volatile bool     ackPending;   // true = warte auf Quittung
  volatile bool     ackReceived;  // true = Quittung eingetroffen
  volatile int      ackRelayIdx;  // erwarteter Relay-Index
  volatile int      ackRelayVal;  // erwarteter Wert
  volatile uint8_t  rs232WaitSeq; // Sequenznummer auf die wir warten
};

ClientState clientStates[5]; // Index: 0=esp1, 1=esp2, 2=esp3, 3=esp4, 4=esp5

// Hilfsfunktion: Index eines Clients anhand des Namens
int clientIndex(const char* name) {
  if (strcmp(name, "esp1") == 0) return 0;
  if (strcmp(name, "esp2") == 0) return 1;
  if (strcmp(name, "esp3") == 0) return 2;
  if (strcmp(name, "esp4") == 0) return 3;
  if (strcmp(name, "esp5") == 0) return 4;
  return -1;
}

uint8_t* clientMAC(int idx) {
  switch(idx) {
    case 0: return MAC_ESP1;
    case 1: return MAC_ESP2;
    case 2: return MAC_ESP3;
    case 3: return MAC_ESP4;
    case 4: return MAC_ESP5;
    default: return nullptr;
  }
}

// Eindeutiger Bezeichner pro Client
const char* CLIENT_NAMES[5] = {"esp1", "esp2", "esp3", "esp4", "esp5"};

// ============================================================================
// ESP-NOW CALLBACKS
// ============================================================================

void onSendCallback(const wifi_tx_info_t* info, esp_now_send_status_t status) {
  // Optional: Fehlerlogging wenn Paket nicht ankam
  if (status != ESP_NOW_SEND_SUCCESS) {
    Serial.printf("[ESP-NOW] Send FAILED to %02X:%02X:%02X:%02X:%02X:%02X\n",
                  info->des_addr[0], info->des_addr[1], info->des_addr[2],
                  info->des_addr[3], info->des_addr[4], info->des_addr[5]);
  }
}

void onReceiveCallback(const esp_now_recv_info_t* info, const uint8_t* data, int len) {
  if (len != sizeof(StatusMsg)) return;

  StatusMsg msg;
  memcpy(&msg, data, sizeof(msg));

  int idx = clientIndex(msg.device);
  if (idx < 0) {
    Serial.printf("[ESP-NOW] Unbekannter Client: %s\n", msg.device);
    return;
  }

  clientStates[idx].online   = true;
  clientStates[idx].lastSeen = millis();
  memcpy(&clientStates[idx].status, &msg, sizeof(msg));

    if (clientStates[idx].ackPending) {
      if (clientStates[idx].ackRelayIdx >= 0) {
        // Relay ACK
        int ri  = clientStates[idx].ackRelayIdx;
        int rv  = clientStates[idx].ackRelayVal;
        if (ri < msg.relay_count && msg.relays[ri] == rv) {
          clientStates[idx].ackReceived = true;
        }
      } else if (clientStates[idx].ackRelayIdx == -1) {
        // RS232 ACK: Warte auf neue Sequenznummer
        if (msg.rs232_seq != clientStates[idx].rs232WaitSeq) {
          clientStates[idx].ackReceived = true;
        }
      }
    }
}

// ============================================================================
// ESP-NOW SENDEN
// ============================================================================

bool sendCmd(const char* target, const char* cmd, int idx, int val, int extra = 0, const char* payload = "") {
  int ci = clientIndex(target);
  if (ci < 0) {
    Serial.printf("[CMD] Unbekanntes Ziel: %s\n", target);
    return false;
  }
  uint8_t* mac = clientMAC(ci);

  CmdMsg msg;
  memset(&msg, 0, sizeof(msg));
  strlcpy(msg.cmd, cmd, sizeof(msg.cmd));
  msg.idx   = (int16_t)idx;
  msg.val   = (int16_t)val;
  msg.extra = (int16_t)extra;
  strlcpy(msg.payload, payload, sizeof(msg.payload));

  esp_err_t result = esp_now_send(mac, (uint8_t*)&msg, sizeof(msg));
  if (result != ESP_OK) {
    Serial.printf("[CMD] esp_now_send Fehler: %d\n", result);
    return false;
  }
  return true;
}

// ============================================================================
// SZENARIEN
// ============================================================================
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

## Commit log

2025-08-10 fritzing windrad kraftwerk
    [gaskraftwerk.fzz, windrad.fzz]
2025-09-23 buttons pumpe
2025-10-03 rs232 communication relay v1
2025-10-03 relays working
2025-10-10 ordnerstruktur und passwortdatei besser
    [Tisch-extured-wood.blend, Tisch.blend, Tischv57.blend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]
2025-10-13 fritzing angefangen
    [Tisch-komplett.fzz]
2025-10-23 fritzing bauteile
    [Tisch-komplett.fzz, bauteile.fzz]
2025-10-23 erste seite vom tisch fertig
    [Tisch-komplett.fzz]
2025-10-24 erste relays tisch 3
    [Tisch-komplett.fzz]
2025-10-24 relay1 neu angeordnet
    [Tisch-komplett.fzz]
2025-10-24 tisch kompleeter aktueller stand
    [Tisch-komplett.fzz]
2025-10-27 relays funktionieren mit website
2025-10-27 claude code, relays working perfectly
2025-10-28 funktioniert nichtmehr mit r und n
2025-10-28 esp1 & esp2 temperatur
2025-11-04 kabel verschönert
    [Tisch-komplett.fzz]
2025-11-04 bessere kabel
    [Tisch-komplett.fzz]
2025-11-08 Refactor scenario execution to ESP-Host and update UI
    Moved scenario execution logic from Flask backend to ESP-Host firmware. ESP_Host.ino now supports scenario endpoints and executes relay sequences directly. The Flask app and frontend were updated to 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
2025-11-08 scenarios funktionieren. aber einzelne relays weg
2025-11-08 relays funktionieren
2025-11-17 funktioniert soweit. vor esp3 update
    [Tisch-extured-wood.blend, Tisch.blend, Tischv57.blend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]
2026-02-09 antigravity landing page
2026-02-10 Reorganize landing controls by system
    Restructure the landing page to group controls and status by system (Coal, Gas, Wind, Train, Reserve) rather than by ESP. Update landing.html structure and landing.js logic to distribute relays/statuses into the new system cards (including index-based relay mapping) and fix related JS issues. Adjust landing.css for the new system-card/grid layout and visual styles. Also update app.py and dashboard.html routing/links and add a detailed implementation conversation file (Implementing Connection Status Indicators.md) documenting the changes and rationale.
2026-02-17 4 relays, 1 druck extra
2026-02-22 sensoren gehen nicht
2026-02-23 Update ADC pin assignments and print logic
    Replace sensor ADC pin array with ADC-capable pins {36,39,34,35,32}. Fix variable names in printStatus() to use currentValues and pressureValues. Call readSensors() before printing and change the status print interval check from 3000ms to 500ms so prints use fresh sensor readings.
    [ESP_4.ino]
2026-03-01 5 relays esp4
2026-03-02 connection stability esp4 - not working properly
    [ESP_1.ino, ESP_2.ino, ESP_3.ino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]
2026-03-02 feat: Implement central web dashboard with ESP device monitoring, relay control, and ESP4 firmware.
2026-03-02 calculation of pressure/distance on app.py
2026-03-07 macaddressen rihtig. relays nicht funktionsfähig
2026-03-08 esp2 rename, connection. error msg
    [ESP_2.ino, ESP_Host.ino]
2026-03-09 Add CLAUDE.md with repository guidance
    Add CLAUDE.md to document repository setup and usage for Claude Code and contributors. The file includes a project overview, common commands for running the Flask web app and uploading Arduino/ESP fi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
2026-03-10 Add detailed README with full project docs
    Replace the placeholder README with a comprehensive project documentation for the Energiesystemmodell Lausitz. Adds project overview, system architecture and communication flow, features, hardware and software stacks, installation and setup instructions (ESP firmware + Flask server), usage and API endpoints, project structure, future improvements, and license notes. This provides developers and operators with step-by-step setup, device mappings, scenario examples, and debugging endpoints to run and extend the system.
2026-03-10 leds test
2026-03-11 led 162 blau rot entgegegesetzt
2026-03-14 2 temp sensors; scrolling v2; debug output esp1-4
2026-03-17 max led length for red blue fluss
2026-03-19 flow buttons
2026-03-22 Add ESP5 LED support and web sync
    Introduce ESP5 LED node and integrate frontend/backend control and syncing.
    - Add new ESP firmware (ESP_5.ino) that receives ESP-NOW LED commands, manages 7 strips with up to 4 segments each, renders with FastLED and sends a heartbeat status (MAC placeholder left TODO).
    - Extend ESP_Host to support a fifth client (esp5): add MAC placeholder, expand client arrays, register peer, expose /state/esp5, and forward new /led? HTTP paths to ESP5 via ESP-NOW.
    - Add Flask LED blueprint (routes/leds.py) providing /api/leds/sync and /api/leds/test endpoints which map logical flows to LED strips and forward commands to esp5 using host_forward.
    - Add LED_MAPPING to confi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
2026-03-22 Document ESP5 LED controller and add LED APIs
    Add documentation for a new ESP5 LED strip controller across AGENTS.md and README.md. Updates include: adding ESP_5.ino to agent list, including ESP5 in the architecture/diagram and device table, ref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
